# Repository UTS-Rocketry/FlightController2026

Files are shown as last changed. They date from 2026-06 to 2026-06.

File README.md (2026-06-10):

# ODIN - UTS Rocketry – Flight Controller 2026

b32aecdc31f343ea89f31d750d7f50b3_T

## Version 1.0 - First Flight Test Release

Primary avionics flight controller for the 2026 AURC rocket.

ODIN is a 3.3V STM32-based embedded flight controller designed to manage flight-state detection, onboard sensor acquisition, telemetry transmission, and flight data logging. This release represents the first hardware-and-firmware test release for an upcoming flight test.

The current firmware is intentionally simple and robust. It runs on a superloop architecture without DMA and uses a watchdog for fault recovery. The system has been tested using hardware-in-the-loop simulated flight data and has operated reliably during testing.

---

## System Overview

### Microcontroller

* STM32 F4-series microcontroller
* 3.3V logic domain
* SWD programming and debugging via ST-Link
* Optional USB device support planned for future debug and firmware workflows
* Hardware timers available for deterministic event timing
* Watchdog enabled for fault recovery

---

## Current Firmware Architecture

The first flight test firmware uses a simple superloop design.

### Current Implementation

* No RTOS
* No DMA
* Polling-based peripheral handling
* Watchdog-supervised main loop
* Deterministic flight-state logic
* Sensor sampling over shared SPI bus
* Flash-based data logging
* LoRa telemetry transmission
* Hardware-in-the-loop test data support

This architecture was selected for the first test release to reduce complexity and improve reliability during initial flight testing.

---

## Sensors

All primary sensors are currently connected on a shared SPI bus.

### Barometer

* SPI pressure sensor
* Used for altitude estimation
* Used for flight-state detection and validation
* Locally decoupled according to sensor requirements

### IMU

* SPI accelerometer and gyroscope
* Used for:

  * Boost detection
  * Apogee validation
  * Motion and orientation monitoring
* Interrupt-capable lines available for future firmware revisions

### GPS

GPS support is planned for ODIN but is not included in the current first-flight test release due to hardware issues.

Planned GPS functions include:

* Real-time position tracking
* Post-flight recovery support
* Telemetry downlink of GPS coordinates
* Position logging to onboard storage

---

## Telemetry - SX1262 LoRa

ODIN uses an SX1262-based LoRa radio for long-range telemetry transmission.

### Current Telemetry Features

* LoRa telemetry transmission enabled
* Flight-state downlink
* Sensor-derived flight data downlink
* Battery voltage downlink
* Packet scheduling is handled in the main superloop

### Planned / Future Telemetry Features

* GPS coordinate transmission
* More complete telemetry packet structure
* Configurable LoRa parameters
* Improved fault handling for radio errors

---

## Data Logging

### Current Storage

The current first flight test release uses onboard flash memory as the primary data storage medium.

Flash logging is used because the microSD card interface was dropped from the current release after wiring issues were found during testing.

### microSD Status

microSD logging was planned for this revision; however, the SD card wiring was incorrect, and the SD card interface is not used in this test release.

### Logged / Stored Parameters

The current firmware is intended to store key flight data, including:

* Timestamp or sample counter
* Raw pressure
* Calculated altitude
* IMU acceleration
* IMU gyroscope data
* Flight-state transitions
* Battery voltage
* Event flags

---

## Power Architecture

* Main system input rail
* 3.3V regulated logic rail
* ADC-based battery voltage monitoring through resistor divider
* Local decoupling at each IC
* Bulk capacitance near high-current and noise-sensitive devices
* Solid ground reference for digital logic and sensors

### Design Considerations

* All digital logic operates at 3.3V
* Shared SPI bus used for sensors and peripherals
* Short SPI traces where possible
* Source termination is considered for high-speed SPI lines
* Switching regulator noise kept away from sensitive sensor and RF sections
* Ground reference continuity is maintained across the board

---

## Programming & Debugging

### SWD Interface

SWD is the primary programming and debugging interface.

Signals:

* SWDIO
* SWCLK
* GND
* 3.3V reference
* NRST

Used for:

* Firmware flashing
* Breakpoint debugging
* Register inspection
* Fault investigation

### USB

USB support is optional and planned for future development.

Potential future uses:

* CDC virtual COM port for debug output
* DFU firmware update support
* Ground-test data streaming

---

## First Flight Test Release Notes

This release is prepared for the first ODIN flight test.

### Included

* STM32-based flight controller firmware
* Superloop firmware architecture
* Watchdog fault recovery
* SPI sensor acquisition
* Barometer-based altitude estimation
* IMU data acquisition
* LoRa telemetry transmission
* Flash-based data logging
* Battery voltage monitoring
* Hardware-in-the-loop simulated flight data testing

### Not Included in This Release

* GPS support
* microSD card logging
* DMA-based peripheral handling
* RTOS task scheduling
* Full sensor-fusion stack
* Final telemetry packet format
* Final competition firmware architecture

### Known Issues

* The microSD card interface is not used due to incorrect wiring
* GPS is not included in this release due to hardware issues
* Firmware currently uses polling rather than DMA
* Current release prioritises reliability and simplicity over final feature completeness

---

## Core Features

* Sensor initialisation and health checks
* Watchdog-supervised main loop
* Deterministic flight-state transitions
* Flash-based onboard data storage
* LoRa telemetry transmission
* Battery voltage monitoring
* Brownout and fault-awareness support
* Hardware-in-the-loop simulation data testing

---

## Development Roadmap

Future firmware and hardware revisions are expected to include:

* GPS integration
* Corrected microSD card interface
* Improved onboard logging backend
* DMA support for selected peripherals
* More complete sensor fusion
* Refined telemetry packet scheduling
* Expanded fault detection and recovery
* USB debug and DFU support
* Full competition-ready flight software

---

## Contributors
* Michael Basangan: Software Lead
* Aditya Sriram: Advisor

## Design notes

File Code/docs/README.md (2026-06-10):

# FlightComputer2026 — Documentation

Avionics flight software for **ODIN**, an STM32F405-based rocket flight computer.
This folder is the human-readable map of the firmware: what each module does, how
the system fits together, and where the code needs hardening before flight.

> **Scope.** These docs cover the *application* code under `Core/App/` plus a
> high-level view of `Core/Src/`. Vendor / auto-generated code (CubeMX init,
> ST sensor register drivers `*_reg.c`, the FatFs middleware) is intentionally
> **not** documented here — it is upstream code we did not author.

---

## Document map

| Document | What it covers | Read it when… |
|---|---|---|
| **[SYSTEM_OVERVIEW.md](SYSTEM_OVERVIEW.md)** | End-to-end architecture, execution model, data flow, the flight state machine, sensor fusion, the actuator/control story, comms, and interview talking points. | You want the big picture, or you're prepping to explain this system out loud. |
| **[CONCURRENCY_SAFETY.md](CONCURRENCY_SAFETY.md)** | Every place the code shares state across execution contexts, the memory-safety and atomicity bugs found, and a prioritized refactor plan. | You're about to make the firmware concurrent, or you want to fix the known landmines. |
| **[FSM_DISPATCH_TABLE.md](FSM_DISPATCH_TABLE.md)** | Design guidance (no code) for replacing the FSM `switch` with a function-pointer dispatch table — shape, gotchas, migration plan. | You're refactoring the flight state machine. |
| **[AppDrivers.md](AppDrivers.md)** | Hardware driver layer: sensors (baro, IMU, high-g accel), LoRa radio, flash, CAN, GPS/USB stubs. | You're touching a peripheral or adding a new one. |
| **[ApplicationLayer.md](ApplicationLayer.md)** | The "brains": sensor aggregation, Kalman filter, flight state machine, pyro/recovery logic, packet (de)serialization, and CAN tasks. (The airbrake stub was removed — control runs on KESTREL.) | You're working on flight logic, fusion, or control. |
| **[Outputs.md](Outputs.md)** | Telemetry serialization, LoRa downlink, flash data logging, LEDs/buzzer. | You're changing what leaves the board (radio, flash, indicators). |

---

## 30-second architecture summary

```
            ┌──────────────────────────────────────────────┐
            │            main.c  —  bare-metal superloop      │
            │   (no RTOS; tasks time-sliced by HAL_GetTick)   │
            └──────────────────────────────────────────────┘
                     │            │            │
        ┌────────────▼──┐  ┌──────▼──────┐  ┌──▼────────────┐
        │  Application  │  │   Outputs   │  │  AppDrivers    │
        │    Layer      │  │             │  │                │
        │ sensors/KF/   │  │ telemetry/  │  │ baro,IMU,accel │
        │ FSM/pyro/     │  │ flash log/  │  │ LoRa,flash,CAN │
        │ CAN tasks     │  │ LED+buzzer  │  │                │
        └───────────────┘  └─────────────┘  └────────────────┘
```

- **MCU:** STM32F405 @ 144 MHz, Cortex-M4F, no dynamic memory, no OS.
- **Sensing:** BMP388 barometer, LSM6DSOX IMU (accel+gyro), H3LIS331DL high-g accel — all on **SPI1**.
- **Fusion:** 3-state Kalman filter (altitude / velocity / accel-bias).
- **Decisions:** 8-state flight state machine drives pyro deployment.
- **Actuation:** pyro channels (drogue/main/aux) on this board; airbrake/fin control runs on the separate **KESTREL** control board (its own Kalman + FSM), coordinated over CAN.
- **Downlink:** LoRa (SX1276) @ 915 MHz on **SPI2**; data logging to W25Q128 16 MB flash on **SPI3**.

---

## Status legend used throughout these docs

| Symbol | Meaning |
|---|---|
| ✅ | Implemented and exercised |
| 🟡 | Implemented, not yet flight-validated / has open issues |
| 🧩 | Stub — file exists but is empty / planned |
| ⚠️ | Known bug or hazard (see [CONCURRENCY_SAFETY.md](CONCURRENCY_SAFETY.md)) |

---

*Generated from a read-through of the `dev` branch. File/line references are
accurate as of that read; re-verify after large refactors.*

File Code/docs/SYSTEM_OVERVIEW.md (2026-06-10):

# System Overview

> **Purpose of this document.** Give you a complete, accurate mental model of the
> flight computer so you can explain it confidently — including the parts a
> software/controls interviewer will probe: real-time execution, the control &
> actuation path, sensor fusion, and the engineering trade-offs you made.
>
> The last section, **[Explaining this in an interview](#explaining-this-in-an-interview)**,
> is written specifically for that conversation.

---

## 1. What it is, in one paragraph

ODIN is the flight computer for a high-power rocket. It reads three motion/pressure
sensors, fuses them into a clean estimate of **altitude and vertical velocity** with a
Kalman filter, runs an **8-state flight state machine** that decides when the rocket
has launched / burned out / reached apogee / should deploy recovery, and **fires pyro
channels** to deploy drogue and main parachutes. Throughout flight it **streams telemetry
over a LoRa radio** and **logs every sample to onboard flash**. It runs bare-metal (no
RTOS) on an STM32F405 as a single timed superloop. Active control (airbrakes/fins for
apogee targeting) runs on a **separate control board (KESTREL)**, which carries its own
sensors and runs its own copy of the same Kalman filter and state machine; the two boards
coordinate over a CAN bus.

---

## 2. Hardware platform

| Block | Part | Interface | Notes |
|---|---|---|---|
| MCU | STM32F405 (Cortex-M4F) | — | 144 MHz, hardware FPU, static memory only |
| Barometer | BMP388 | **SPI1** | Primary altitude source (pressure → altitude) |
| IMU | LSM6DSOX (accel + gyro) | **SPI1** | ±16 g accel, ±2000 dps gyro, launch/burnout detect |
| High-g accel | H3LIS331DL | **SPI1** | ±200 g — survives boost when the IMU saturates |
| Radio | LoRa SX1276 | **SPI2** + EXTI | 915 MHz telemetry downlink |
| Data log | W25Q128 NOR flash | **SPI3** | 16 MB, 64-byte records, ~262 k samples |
| SD card | (FatFs) | SPI | 🧩 present but **disabled** — wired wrong (see `main.c`) |
| Pyro out | 3× MOSFET channels | GPIO | Drogue, Main, Aux igniters |
| Pyro sense | 2× continuity | ADC1, ADC2 | Checks igniter continuity before flight |
| Indicators | Buzzer + RGB LED | GPIO / TIM2 PWM | Buzzer used; RGB PWM configured, not driven |
| Console | UART4 @ 115200 | UART | `printf` is redirected here (`_write` in `main.c`) |
| GPS | (planned) | UART5 | 🧩 stub |
| Vehicle bus | CAN2 | CAN | 🧩 peripheral init'd, driver stubbed |

**Bus allocation is a deliberate design choice** and worth calling out: the three
sensors share **SPI1**, while the **radio (SPI2)** and **flash (SPI3)** each get their
own bus. That separation means a slow radio transmit can't stall a flash write (in a
concurrent design) and the high-rate sensor reads aren't competing with bulk I/O.

---

## 3. Software architecture

The code is organized in three layers under `Core/App/`, with a thin generated
HAL/CubeMX base under `Core/Src/` and `Core/Inc/`.

```
 Core/Src/main.c   ── the superloop + all peripheral init (CubeMX) + global sensorData
        │
        ▼
 ┌─────────────────────────────────────────────────────────────────────┐
 │  Outputs/                 telemetry.c · logger(stub) · indicators.c   │  what leaves the board
 ├─────────────────────────────────────────────────────────────────────┤
 │  ApplicationLayer/        flight_sensors · kalman · flight_state      │  the brains
 │                           pyro · Lora_App · crc16 · W25Q128_HAL       │
 │                           CANTasks(stub)  ·  airbrake → KESTREL board │
 ├─────────────────────────────────────────────────────────────────────┤
 │  AppDrivers/              BMP388 · lsm6dsox · h3lis331dl · LoRa        │  hardware
 │                           W25Q128 · CAN · GPS(stub) · USB(stub)       │
 └─────────────────────────────────────────────────────────────────────┘
        │
        ▼
 ST HAL + CubeMX (Core/Src) · FatFs middleware (vendor)
```

**Layering rule of thumb:** higher layers call down, never up. A driver never knows
about flight state; the FSM never touches SPI. The one place this is slightly blurred
is telemetry/logging, which is split between `Outputs/` and `ApplicationLayer/` — noted
in [Outputs.md](Outputs.md).

---

## 4. Execution model — the superloop

There is **no operating system**. `main()` initializes everything, then runs a single
infinite loop. Inside the loop, each "task" is gated by a millisecond deadline measured
against `HAL_GetTick()` (the 1 kHz SysTick). This is a **cooperative, time-sliced
scheduler in ~30 lines** — sometimes called a "timing wheel" or "superloop."

```c
while (1) {
    uint32_t now = HAL_GetTick();

    if (now - last_imu  >= 10)  { read IMU; kalman_predict(accel, 0.01); }   // 100 Hz
    if (now - last_baro >= 40)  { read baro; kalman_update(altitude);     }   //  25 Hz
    FSM_update(&sensorData);                                                  // every pass
    if (now - last_lora  >= 200 && state >= PAD) lora_tx_telemetry(...);       //   5 Hz
    if (now - last_flash >= 40  && state >= PAD) flash_log_telemetry(...);     //  25 Hz
}
```

(Source: `Core/Src/main.c` lines ~207–259.)

**Cadence summary**

| Task | Period | Rate | Gated on |
|---|---|---|---|
| IMU read + Kalman *predict* | 10 ms | 100 Hz | always |
| Baro read + Kalman *update* | 40 ms | 25 Hz | always |
| FSM update | every pass | ~loop rate | always |
| LoRa telemetry TX | 200 ms | 5 Hz | state ≥ PAD |
| Flash logging | 40 ms | 25 Hz | state ≥ PAD |

**Interrupts.** Only one application interrupt is wired: LoRa **DIO0 → EXTI9_5**, whose
handler sets `lora_tx_done_flag` (`Lora_App.c`). SysTick runs the HAL tick (and
decrements two leftover SD-card timeout counters). Everything else is polled.

**Why this matters (and why an interviewer will ask):** a superloop is simple,
deterministic, and has no scheduler overhead or stack-per-task cost — great for a first
flight computer. Its weakness is that **the loop is only as fast as its slowest blocking
call**, and any unbounded wait hangs *everything*. Several such blocking calls exist
today and are catalogued in **[CONCURRENCY_SAFETY.md](CONCURRENCY_SAFETY.md)** — that
document is essentially the "what breaks when we add real concurrency or active control"
analysis.

---

## 5. Data flow — sensor to decision to action

```
  BMP388 ─┐                               ┌─► LoRa downlink (5 Hz)
  LSM6DSOX├─► flight_sensors ─► sensorData ┼─► flash log    (25 Hz)
  H3LIS331┘     (raw + cal)       │        └─► FSM ─► pyro fire (drogue/main)
                                  │                    │
                                  └─► Kalman filter ◄──┘  (alt + velocity feed both
                                       (alt, vel)          apogee detection and the
                                                           future control loop)
```

1. **Acquire.** `flight_sensors_update_*()` reads each sensor over SPI1, applies the
   calibration offset captured at startup, and writes engineering units into one global
   `FlightSensorData sensorData` struct.
2. **Fuse.** The IMU's vertical acceleration drives `kalman_predict()`; the barometer's
   altitude drives `kalman_update()`. The filter outputs a smoothed altitude and a
   velocity estimate that the raw sensors can't give directly.
3. **Decide.** `FSM_update()` reads `sensorData` (IMU accel, Kalman velocity/altitude)
   and advances the flight state, with debounce counters so a single noisy sample can't
   trigger a transition.
4. **Act.** State entries fire pyro channels (`pyro_fire_main/drogue`). This is the
   actuation path today.
5. **Report.** Telemetry is serialized (big-endian, CRC16-protected) and pushed to both
   the radio and flash.

The single shared `sensorData` struct is the system's "blackboard." It's fine in a
superloop (one reader/writer, sequential), but it becomes the central hazard the moment
anything runs concurrently — see the safety doc.

---

## 6. The flight state machine

`flight_state.c` implements a classic entry-action state machine. Thresholds live in
`flight_config.h` so tuning never touches logic.

```
 IDLE ──(10 s auto-arm)──► PAD ──(accel ≥ 3 g ×5)──► BOOST
                                                       │ (accel ≤ 2 g ×5, or 10 s timeout)
                                                       ▼
   LAND ◄─(low alt+vel, or timeout)─ PARAFOIL ◄─ DROGUE ◄─ APOGEE ◄─ COAST
                                                   │   ▲                 │ (vel < −0.5 m/s ×10,
                                          (main fired)│                 │  or 30 s timeout)
                                                       └─ deploy logic ──┘
```

| State | Enters when | Key action |
|---|---|---|
| `IDLE` | boot | wait; auto-arms after 10 s (`ARM_AUTO_DELAY_MS`, a temporary stand-in for a LoRa arm command) |
| `PAD` | armed | watch for launch: IMU z-accel ≥ 3 g for 5 consecutive samples |
| `BOOST` | launch detected | motor burning; watch for burnout (≤ 2 g ×5) or 10 s timeout |
| `COAST` | burnout | unpowered ascent; **the window where the KESTREL board actuates airbrakes/fins** |
| `APOGEE` | velocity goes negative (×10) or 30 s timeout | record peak altitude; fire recovery |
| `DROGUE` | after apogee deploy | descend under drogue; fire main at `MAIN_DEPLOY_ALT_M` (300 m) |
| `PARAFOIL` | main deployed | controlled descent; the parafoil is itself an actuated recovery system |
| `LAND` | low altitude + near-zero velocity, or timeout | done |

**Debounce pattern.** Every transition that's driven by a sensor requires *N consecutive*
qualifying samples (`LAUNCH_CONFIRM_SAMPLES`, `APOGEE_CONFIRM_SAMPLES`, …). This is the
software equivalent of a Schmitt trigger and is exactly the kind of robustness detail
worth pointing out.

**Redundant apogee detection.** Apogee can trigger two ways — velocity sign change *or* a
hard timeout — so a sensor dropout can't strand the vehicle without deploying recovery.
The same belt-and-suspenders pattern (event *or* timeout) appears in BOOST, COAST,
DROGUE, and PARAFOIL. That defensive design is a genuine strength to highlight.

> ⚠️ **Confirmed logic bug in the low-apogee path.** At `APOGEE` entry, if the recorded
> apogee is below `MAIN_DEPLOY_ALT_M` the code fires **main** directly — an *intentional*
> low-apogee contingency (skip the drogue phase and get the main out), otherwise it fires
> **drogue**. The intent is right, but the branch sets `main_fired = 1` and then
> transitions to `STATE_DROGUE`, whose **only** exits (`flight_state.c:148,153`) both
> require `main_fired != 1`. So the FSM gets **permanently stuck in `DROGUE`**: it never
> reaches `PARAFOIL`/`LAND`, landing is never detected, and telemetry reports `DROGUE` for
> the rest of the flight (the chute still deploys — a state-machine dead-end, not a deploy
> failure). Fix: transition straight to `STATE_PARAFOIL` in the low-apogee branch. Full
> write-up in safety doc
> [M3](CONCURRENCY_SAFETY.md#-m3--low-apogee-deploy-leaves-the-fsm-stuck-in-drogue).

---

## 7. Sensor fusion — the Kalman filter

`kalman.c` is a **3-state linear Kalman filter**:

- **State:** `[ altitude, velocity, accel_bias ]`
- **Predict** (100 Hz, from IMU): integrates acceleration into velocity and altitude,
  subtracts gravity and the estimated accelerometer bias, clamps to ±16 g, and rejects
  NaN/Inf inputs.
- **Update** (25 Hz, from baro): corrects the state toward the measured altitude; the
  filter learns the accelerometer bias over time, which is what keeps the integrated
  velocity from drifting.
- **Covariance** `P` is a full 3×3 propagated as `P = F·P·Fᵀ + Q`, with the
  measurement step `K = P·Hᵀ·S⁻¹`.

**Why fuse at all?** The barometer gives absolute altitude but is noisy and slow; the
accelerometer is fast but integrating it drifts. Fusing them yields a velocity estimate
good enough to detect apogee — and, importantly, good enough to **feed a control loop**.
That velocity/altitude estimate is the natural feedback signal for airbrake/fin control.

> Implementation notes: `dt` is now computed from real elapsed time (`main.c:211`, fixed
> since the first review); the process/measurement noise (`Q`/`R`) are still fixed
> constants — a reasonable v1 choice and an easy tuning lever to mention.

---

## 8. The control and actuation path

> *The most relevant section for a controls / actuator software role.*

This is the part to be fluent in, since the role is about actuator/fin-control software.
It's useful to frame the vehicle's actuation as **three tiers**, and to be clear which
board owns each — **ODIN** (this flight computer) vs. **KESTREL** (the control board):

### Tier 1 — Pyrotechnic actuation (implemented ✅)

`pyro.c` drives three igniter channels through MOSFETs and reads two ADC continuity
checks. The FSM commands them at the right flight phase. This is *open-loop, one-shot*
actuation: fire for a fixed pulse (`PYRO_FIRE_DURATION_MS = 500 ms`) and latch a "fired"
flag so it can't double-fire.

> ⚠️ `pyro_fire_*()` holds the line high with a **blocking `HAL_Delay(500)`**, so firing
> stalls the entire superloop for half a second — no sensor reads, no estimation, no
> telemetry during that window. For pyro that's *arguably* tolerable; for a closed-loop
> actuator it is not. This is the cleanest example of why the loop must go non-blocking
> before active control is added. (Catalogued as **C1** in the safety doc.)

### Tier 2 — Continuous control surfaces / airbrakes ⟶ *runs on the KESTREL control board, not ODIN*

Active airbrake/fin control does **not** run on this flight computer. It lives on a
**separate control board (KESTREL)** with its own sensors that runs **its own copy of the
same Kalman filter and flight state machine**. ODIN's job is sensing, estimation, recovery
(pyro), logging and downlink; KESTREL independently estimates state and drives the control
surfaces. *(The empty `ApplicationLayer/ControlLoop/airbrake.{c,h}` stubs in this repo are
therefore removed (staged for deletion) — that code belongs on KESTREL.)*

**Why duplicate the KF + FSM on both boards?** So the deploy decision doesn't depend on
ODIN being alive or the CAN link being up — and, critically, so KESTREL can **gate airbrake
deployment to the `COAST` state on its own**. Airbrakes must never deploy during boost
(high-g) or the airframe could be damaged; by independently detecting burnout→COAST,
KESTREL has a self-contained safety interlock. This is **redundant / distributed
estimation**: two boards reach the flight-phase decision independently.

The controller itself (on KESTREL): feedback = Kalman altitude/velocity (+ gyro for
attitude); setpoint = a target apogee; output = a PWM servo command modulating drag to
bleed excess energy (classic apogee-targeting). A PID or gain-scheduled law on
velocity-vs-altitude is the usual approach. Authority is gated to `COAST`.

**What to say in an interview:** *"Active control runs on a dedicated board that
independently re-derives flight phase with the same Kalman filter + state machine, so the
airbrakes can only deploy in coast — even if the main flight computer or the bus drops out.
That redundant-estimation interlock is what stops a control surface from firing under boost
loads."* That shows you think about actuator **safety interlocks** and **failure
independence**, not just the control law — and that **control is only as good as the
real-time guarantees underneath it**.

### Tier 3 — Distributed actuation over CAN (planned 🧩 — `CANTasks/can_tasks.c`)

The CAN layer (`AppDrivers/CAN/CAN.h`) defines a small **vehicle bus protocol**:

- **Nodes:** `ODIN` (this flight computer), `KESTREL` (control/actuator board),
  `RAVEN` (camera), `HUGINN` (CAN sniffer/debug).
- **Messages:** heartbeat, FSM-state broadcast, **KESTREL commands** (activate /
  deactivate / **deploy parafoil**), camera commands, **actuator status**
  (`airbrake_pos`, `parafoil_dep`), ACK, error.
- **Addressing:** 11-bit ID packed as `(node << 7) | msg`.

The split the message set implies: **ODIN broadcasts flight state + estimation and issues
high-level commands (e.g. deploy-parafoil); KESTREL runs its own estimation, drives the
airbrakes/fins, and reports `airbrake_pos` / `parafoil_dep` status back.** Both boards
estimate independently (see Tier 2) — CAN coordinates them, but neither blindly trusts the
other for the safety-critical phase decision. That's a textbook *distributed-controls* bus
pattern. The peripheral is initialized (`CAN2` in `main.c`) but `CAN.c` and `can_tasks.c`
are not yet implemented — `CANTasks/` stays on ODIN (it still broadcasts state).

> ⚠️ Landmine to fix before wiring CAN in: `CAN.h` and `Lora_App.h` both define enums
> named `IDLE`, `ARMED`, … — including both in one translation unit won't compile.
> See safety doc item **C8**.

---

## 9. Communications

### LoRa telemetry downlink (✅, 🟡)

- SX1276 at **915 MHz, SF7, 125 kHz BW, CR 4/5, +17 dBm (PA_BOOST), CRC on** (`Lora_App.c`).
- **5 Hz** downlink once armed.
- Packet: a fixed **58-byte** frame — 3-byte header (sync `0xAA`, type, sequence),
  13 big-endian float fields (alt, pressure, temp, 3× high-g, 3× IMU accel, 3× gyro,
  Kalman velocity), 1 state byte, **CRC16-CCITT** (poly `0x1021`) over the first 56 bytes.
- Serialization is hand-rolled and endian-explicit (`telemetry_serializer` in
  `Lora_App.c`) — good practice for a wire format that a ground station must parse.

> ✅ The earlier `lora_tx_telemetry` buffer overflow (**M1**) is now fixed (`buff[62]`). The
> remaining radio issues are the **busy-poll that ignores the DIO0 done-interrupt**
> (**C2**/**C3**) and the new **RX command path blocking ≤1 s** (**N1**). There's also an
> authenticated uplink command path and a pre-launch continuity broadcast now (see
> [Outputs.md](Outputs.md)).

### CAN vehicle bus (🧩)

See [§8 (Tier 3)](#8-the-control-and-actuation-path).
Protocol defined, transport not yet implemented.

---

## 10. Memory & data logging

- **No heap.** Everything is statically allocated — global structs, file-scope `static`
  driver state, stack buffers. No `malloc`, no fragmentation, deterministic footprint.
  This is the right call for flight code and worth stating plainly.
- **Flash log:** `W25Q128_HAL.c` writes fixed **64-byte records** sequentially to the
  16 MB NOR flash, auto-erasing each 4 KB sector as it reaches it. ~262 000 records ≈
  ~2.9 hours at 25 Hz. `flash_dump_serial()` replays them over UART for post-flight
  analysis.
- **SD card:** a FatFs + SPI SD path exists (`fatfs_sd.c`) but is **disabled** — the
  comment in `main.c` notes it's wired wrong. The leftover `Timer1/Timer2` SysTick
  counters belong to this dead path.

---

## 11. Key engineering trade-offs (have an opinion on each)

| Decision | Chosen | Why it's defensible | The cost / when you'd change it |
|---|---|---|---|
| **Superloop vs RTOS** | Superloop | Simple, deterministic, no scheduler/stack overhead, easy to reason about for v1 | One blocking call stalls everything; no priority. Move to RTOS (or at least non-blocking + ISR/DMA) when adding closed-loop control. |
| **Polling vs interrupt/DMA SPI** | Polling | Straightforward, no race windows in a superloop | CPU burns cycles waiting; bus-bound. DMA + ISR needed for headroom once a control task exists. |
| **Static vs dynamic memory** | Static | No fragmentation, bounded RAM, flight-safe | Less flexible; you size for worst case. (Correct trade for avionics.) |
| **One shared `sensorData`** | Global blackboard | Zero copies, simple in a single-context loop | Becomes a data race the instant anything is concurrent; needs snapshotting/double-buffer. |
| **Hand-rolled telemetry serializer** | Manual big-endian | Explicit, portable wire format, no library | Verbose, easy to get a length wrong (and one is — see C2). |
| **Three sensors on one SPI bus** | SPI1 shared | Saves pins/buses; radio & flash isolated | Needs bus arbitration if reads ever move off the single loop. |

---

## 12. Explaining this in an interview

### The 60-second pitch
> "I built the flight software for a rocket flight computer on an STM32F405. It fuses a
> barometer and two accelerometers through a Kalman filter into an altitude/velocity
> estimate, runs an 8-state flight state machine that decides launch, burnout, apogee and
> recovery, and fires the parachute pyros. It logs everything to flash and streams
> telemetry over LoRa. It's bare-metal — a single timed superloop, no RTOS, all static
> memory. Active control — airbrakes for apogee targeting — runs on a separate control
> board that re-derives flight phase independently, coordinated over CAN."

### If they push on the **control / actuator** angle (your role)
- Lead with the **three actuation tiers** (§8): pyro recovery on ODIN, airbrake control on
  the KESTREL board, distributed CAN actuation tying them together.
- Emphasize that **the hard prerequisites for control already exist and work**: a clean
  velocity estimate and a state machine that defines exactly when actuation is authorized
  (the COAST window). The control board reuses both, running them **independently** so it
  can gate airbrake deployment to coast on its own — a **redundant-estimation safety
  interlock** that prevents deploying a control surface under boost (high-g) loads.
- Show you understand the *systems* dependency: **"a controller is only as good as the
  real-time loop under it."** The current superloop has blocking calls (pyro `HAL_Delay`,
  LoRa busy-poll) that would inject jitter into a control task — so step one toward
  active control is making the loop non-blocking / moving I/O to DMA+ISR. You can point
  to the exact lines.
- Mention the **CAN protocol design** (ODIN↔KESTREL, `airbrake_pos` feedback) as
  evidence you think about distributed actuation and closed-loop status, not just one MCU.

### If they push on **real-time / concurrency**
- Explain the superloop scheduler and its cadence table (§4), then be honest about its
  limits and that you've already catalogued them ([CONCURRENCY_SAFETY.md](CONCURRENCY_SAFETY.md)).
- Best signal you can give: *"Here are the exact shared-state hazards and the order I'd
  fix them in."* Walk the priority list. Interviewers love a candidate who already knows
  where their own bugs are.

### If they push on **estimation**
- 3-state KF, why fuse (baro = absolute but noisy/slow, accel = fast but drifts), how the
  bias state absorbs accelerometer offset. Mention the fixed `dt` and fixed noise as the
  obvious tuning improvements.

### Likely hard questions — and honest answers
| Question | Strong answer |
|---|---|
| "What happens if a sensor hangs?" | Today the read loops busy-wait with no timeout, so it would hang the whole computer — that's my #1 fix (add bounded timeouts; safety doc C4). |
| "Why no RTOS?" | Simplicity and determinism for v1; I'd adopt one (or non-blocking + DMA) precisely when adding the control task, because that needs a fixed-rate, jitter-bounded slot. |
| "How do you know apogee?" | Kalman velocity crossing negative, debounced over 10 samples, **with** a timeout fallback so a baro dropout still deploys recovery. |
| "Is your telemetry robust?" | CRC16 per packet and a sequence number so the ground station detects drops/corruption. (I also have a buffer-length bug in the TX path I've already identified.) |
| "How would you add airbrakes?" | On the KESTREL control board, not the flight computer: reuse the same Kalman + FSM so it independently knows it's in COAST, run a controller on velocity/altitude, output PWM to a servo, keep the loop non-blocking for a fixed rate. Gating to COAST is the key safety interlock — never actuate under boost. |

### What I'd build next (shows direction)
1. Make the loop non-blocking (kill `HAL_Delay` in pyro/buzzer; ISR/DMA for SPI & LoRa).
2. Add bounded timeouts + fault states to every sensor read.
3. Consume the LoRa DIO0 done-interrupt (C2/C3) and de-block the RX command path (N1).
4. Implement the airbrake control loop on KESTREL (its own KF+FSM, gated to the COAST window).
5. Bring up the CAN link to KESTREL for distributed actuation.

---

## 13. Glossary

| Term | Meaning |
|---|---|
| **ODIN / KESTREL / RAVEN / HUGINN** | CAN node names: flight computer / control board / camera / bus sniffer |
| **Superloop** | A single `while(1)` that runs all tasks cooperatively, no OS |
| **Apogee** | Highest point of flight; where drogue typically deploys |
| **Drogue / Main** | Small stabilizing chute (deploys high) / main chute (deploys low) |
| **Pyro** | Pyrotechnic igniter channel that cuts a line or deploys a chute |
| **ODR / OSR** | Output Data Rate / Oversampling Ratio (sensor config) |
| **EXTI** | STM32 external interrupt line (used for LoRa DIO0) |
| **SF / BW / CR** | LoRa Spreading Factor / Bandwidth / Coding Rate |

---

*See [CONCURRENCY_SAFETY.md](CONCURRENCY_SAFETY.md) for the detailed hazard list this
overview references, and the per-layer docs for module-level API detail.*

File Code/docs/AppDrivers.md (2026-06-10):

# AppDrivers — Hardware Driver Layer

`Core/App/AppDrivers/`

The lowest layer of our own code: one module per physical peripheral. Each driver owns a
**handle struct** (which SPI bus, which CS pin) and exposes a small `HAL_StatusTypeDef`
API. Drivers know nothing about flight state — they just move bytes to and from silicon.

```
AppDrivers/
├── Sensors/     BMP388 (baro) · LSM6DSOX (IMU) · H3LIS331DL (high-g)   ── all on SPI1
├── LoRa/        SX1276 radio                                            ── SPI2 + EXTI
├── Memory/      W25Q128 NOR flash · fatfs_sd (SD, disabled)            ── SPI3 / SPI
├── CAN/         vehicle-bus protocol definitions                       ── CAN2  🧩
├── GPS/         🧩 empty stub                                           ── UART5
└── USB/         🧩 empty stub
```

> **Driver contract (the shared pattern).** Every device driver takes a pointer to a
> handle holding `SPI_HandleTypeDef *hspi` + `cs_port`/`cs_pin`. A private
> `platform_read/platform_write` pulls CS low, sends the register address, transfers, and
> raises CS. Read/write is distinguished by setting the register's MSB(s). This keeps the
> ST vendor `*_reg` driver layer hardware-agnostic.

---

## Sensors/

Three motion/pressure sensors, **all sharing SPI1** (distinct CS pins). They cover
complementary regimes — see [SYSTEM_OVERVIEW §2](SYSTEM_OVERVIEW.md#2-hardware-platform).

The ST sensors (LSM6DSOX, H3LIS331DL) ship with vendor register drivers
(`lsm6dsox_reg.c/.h`, `h3lis331dl_reg.c/.h`) — **not documented here**, they're upstream.
What *we* wrote are the thin `_hal.c` glue files that bind those drivers to our SPI + CS
and add init/calibration/read helpers.

### BMP388 — barometric altimeter ✅
**Files:** `Sensors/BMP388.c` (.h), self-contained driver (no vendor layer).
**Bus/CS:** SPI1 / `CSBarometer`.

| Function | Purpose |
|---|---|
| `BMP388_Init` | Verify chip ID, soft-reset, configure OSR/IIR/ODR, load factory calibration |
| `BMP388_FindGroundPressure` | Capture ground reference pressure at startup (altitude zero) |
| `BMP388_ReadRawPressTempTime` | Raw burst read of pressure/temperature/sensor-time |
| `BMP388_CompensateRawPressTemp` | Apply the datasheet compensation polynomials |
| `BMP388_FindAltitude` | Pressure → altitude (barometric formula vs. ground pressure) |
| `BMP388_ExternalReadFunction` | One-call read used by `flight_sensors`: returns pressure, temp, altitude |

**Notes:** the compensation math uses the float `Calib_data` struct loaded at init. The
data-ready wait in the read path is an unbounded `do/while` (see
[CONCURRENCY_SAFETY C4](CONCURRENCY_SAFETY.md#-c4--unbounded-sensor-busy-waits-with-no-timeout)).

### LSM6DSOX — 6-axis IMU (accel + gyro) ✅
**Files:** `Sensors/lsm6dsox_hal.c` (our glue) + `lsm6dsox_reg.c/.h` (ST, vendor).
**Bus/CS:** SPI1 / `CS_IMU`.

| Function | Purpose |
|---|---|
| `lsm6dso_init` | ID check, reset, disable I3C, **±16 g** accel, **±2000 dps** gyro, gyro LPF; ODR set to **104 Hz** |
| `lsm6dso_Calib` | Average 100 samples to capture accel/gyro zero offsets (Z accel referenced to 1 g) |
| `lsm6dso_ExternalReader` | Read raw accel + gyro (used every IMU pass) |

**Notes:** code comments say "416 Hz" but the calls set `*_ODR_104Hz` — a comment/code
mismatch worth tidying. The Z-accel from this IMU is what drives launch/burnout detection
and the Kalman predict step. `platform_read/write` here **swallow SPI errors**
(always return 0) — [CONCURRENCY_SAFETY C5](CONCURRENCY_SAFETY.md#-c5--spi-errors-are-silently-swallowed).
The data-ready wait has no timeout (worst case of [C4](CONCURRENCY_SAFETY.md#-c4--unbounded-sensor-busy-waits-with-no-timeout) — no delay either).

### H3LIS331DL — ±200 g high-g accelerometer ✅
**Files:** `Sensors/h3lis331dl_hal.c` (our glue) + `h3lis331dl_reg.c/.h` (ST, vendor).
**Bus/CS:** SPI1 / `CSAccelerometer`.

| Function | Purpose |
|---|---|
| `h3lis331dl_init` | ID check, boot, **±200 g** full scale, HP filter off, **100 Hz** ODR |
| `h3lis331dl_Calibration` | Average 100 samples for offsets (Z referenced to 1 g) |
| `h3lis331dl_externalRead` | Read raw 3-axis acceleration |

**Why it exists:** during boost the airframe can exceed the LSM6DSOX's ±16 g range; the
H3LIS keeps a valid acceleration reading when the IMU saturates. Same C4/C5 notes as the
IMU apply.

---

## LoRa/

### SX1276 — 915 MHz LoRa radio ✅ 🟡
**Files:** `LoRa/LoRa.c` (.h).
**Bus/CS:** SPI2 / `LoRaNssPin`; reset on `LoRaResetPin`; **DIO0 → EXTI9_5** for TX/RX done.

A from-scratch SX1276 driver (register map + ops). Configured by the app layer at 915 MHz,
SF7, 125 kHz, CR 4/5, +17 dBm PA_BOOST, CRC on, explicit header.

| Function | Purpose |
|---|---|
| `lora_init` | Reset, set LoRa mode, program frequency/SF/BW/CR/power/CRC/sync/preamble |
| `lora_TX` | Load FIFO, transmit, **busy-poll** `IRQ_TX_DONE` until done or timeout |
| `lora_RX` / `lora_receive_cont` / `lora_receive_cont_poll` | Single & continuous receive |
| `lora_sleep` / `lora_standby` | Power-mode control |
| `lora_packet_rssi` / `lora_packet_snr` / `lora_version` | Link diagnostics |

**Notes:** `lora_TX` busy-polls the IRQ register
([C2](CONCURRENCY_SAFETY.md#-c2--lora_tx-busy-polls-up-to-1-s)) even though the DIO0
done-interrupt is wired up but unused
([C3](CONCURRENCY_SAFETY.md#-c3--lora-tx-done-interrupt-is-set-up-but-never-consumed)).
Receive is implemented but the flight build only transmits.

---

## Memory/

### W25Q128 — 16 MB NOR flash ✅
**Files:** `Memory/W25Q128.c` (.h).
**Bus/CS:** SPI3 / `CSFlashmMemory`.

Clean, low-level driver for the Winbond W25Q128JV. **This is the reference for how to do a
blocking driver right** — note `W25Q128_WaitBusy` uses a real `HAL_GetTick()` timeout
(the pattern the sensor drivers should copy for
[C4](CONCURRENCY_SAFETY.md#-c4--unbounded-sensor-busy-waits-with-no-timeout)).

| Function | Purpose |
|---|---|
| `W25Q128_Init` | CS-high, release power-down, verify JEDEC ID (`EF 40 18`) |
| `W25Q128_ReadJEDECID` | Identity read |
| `W25Q128_ReadData` | Read N bytes from a 24-bit address |
| `W25Q128_PageProgram` | Program up to a 256-byte page (must not cross a page boundary) |
| `W25Q128_SectorErase` / `W25Q128_ChipErase` | 4 KB sector / full-chip erase |
| `W25Q128_WaitBusy` | Poll BUSY with timeout ✅ |
| `W25Q128_PowerDown` / `ReleasePowerDown` | Power management |

Geometry constants (page 256 B, sector 4 KB, 16 MB total) live in `W25Q128.h`. The
flight-facing logging wrapper is `ApplicationLayer/.../W25Q128_HAL.c` — see
[ApplicationLayer.md](ApplicationLayer.md) and [Outputs.md](Outputs.md).

### fatfs_sd — SD card over SPI 🧩 (disabled)
**Files:** `Memory/fatfs_sd.c` (.h).

A Chan-FatFs SPI SD diskio implementation. **Currently disabled** — `main.c` notes the SD
is wired wrong and `f_mount` is commented out. The `volatile uint16_t Timer1/Timer2`
counters defined here (decremented in SysTick) are this driver's I/O timeouts and are
otherwise dead weight right now. Treat this module as parked until the hardware is fixed.

---

## CAN/  🧩

### Vehicle-bus protocol
**Files:** `CAN/CAN.h` (defined), `CAN/CAN.c` (**empty stub**).
**Bus:** CAN2 (peripheral initialized in `main.c`).

No transport code yet, but the **protocol is fully specified** in the header and is the
backbone of the planned distributed-actuation design:

- **Nodes:** `ODIN` (flight computer), `KESTREL` (control/actuator board), `RAVEN`
  (camera), `HUGINN` (sniffer).
- **Messages:** heartbeat, FSM-state broadcast, KESTREL commands (activate / deactivate /
  deploy-parafoil), RAVEN/camera commands, ACK, actuator status (`airbrake_pos`,
  `parafoil_dep`), error.
- **ID format:** `CAN_ID(node,msg) = (node << 7) | msg` (11-bit standard ID).

See [SYSTEM_OVERVIEW §8 (Tier 3)](SYSTEM_OVERVIEW.md#8-the-control-and-actuation-path)
for how this fits the control story, and
[CONCURRENCY_SAFETY C8](CONCURRENCY_SAFETY.md#-c8--duplicate-enum-definitions-collide-across-headers)
for the enum-collision fix needed before implementing it.

---

## GPS/ and USB/  🧩

Empty stubs (`GPS.c/.h`, `USBC.c/.h`). GPS is intended on **UART5**; a `GPSPacket` type
is already reserved in `Lora_App.h` for when position data joins the downlink. USB is a
placeholder (the USB OTG peripheral is initialized in `main.c` but unused).

---

## At-a-glance status

| Driver | Bus | Status |
|---|---|---|
| BMP388 | SPI1 | ✅ |
| LSM6DSOX | SPI1 | ✅ (C4/C5 notes) |
| H3LIS331DL | SPI1 | ✅ (C4/C5 notes) |
| SX1276 LoRa | SPI2 + EXTI | ✅ 🟡 (C2/C3) |
| W25Q128 flash | SPI3 | ✅ (reference impl) |
| fatfs_sd | SPI | 🧩 disabled |
| CAN | CAN2 | 🧩 protocol only |
| GPS / USB | UART5 / USB | 🧩 stubs |

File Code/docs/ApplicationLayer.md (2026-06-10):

# ApplicationLayer — Flight Logic & Fusion

`Core/App/ApplicationLayer/`

The "brains" of the flight computer. This layer turns raw driver reads into a fused state
estimate, decides what phase of flight the vehicle is in, and commands actuation. It calls
*down* into [AppDrivers](AppDrivers.md) and is called *from* the `main.c` superloop.

```
ApplicationLayer/
├── ApplicationHALS/      flight_sensors · kalman · pyro · Lora_App · packets · W25Q128_HAL · crc16
├── FlightStateMachine/   flight_state · flight_config   (refactor → docs/FSM_DISPATCH_TABLE.md)
├── ControlLoop/          airbrake   ❌  ← REMOVED (staged): airbrake control runs on the KESTREL board
└── CANTasks/             can_tasks  🧩  ← CAN comms tasks live here (stays on ODIN)
```

---

## ApplicationHALS/

"HAL" here means *our* application-level hardware abstraction — one tier above the device
drivers. Each module wraps one or more drivers into a flight-friendly API.

### flight_sensors — sensor aggregation & calibration ✅
**Files:** `ApplicationHALS/flight_sensors.c` (.h).

Owns the three sensor handles and the calibration offsets, and presents the unified
`FlightSensorData` struct that the whole system reads/writes.

| Function | Purpose |
|---|---|
| `flight_sensors_init` | Init baro + capture ground pressure, init high-g accel + calibrate, init IMU + calibrate. Returns first failure. |
| `flight_sensors_update_baro` | Read BMP388 → `pressure`, `temperature`, `altitude` (25 Hz) |
| `flight_sensors_update_IMU_accel` | Read H3LIS + LSM6DSOX → high-g, IMU accel, gyro in engineering units, offset-corrected (100 Hz) |

**`FlightSensorData`** (`flight_sensors.h`) is the system blackboard: altitude, pressure,
temperature, velocity, high-g XYZ (mg), IMU accel XYZ (mg), gyro XYZ (mdps),
`kalman_altitude`, `kalman_velocity`, and `flight_state`. It is instantiated once as a
global in `main.c`.

> Footguns: there are **two** velocity fields (`velocity` and `kalman_velocity`) — only
> `kalman_velocity` is populated/used. The struct is shared with no snapshot protection
> ([CONCURRENCY_SAFETY C6](CONCURRENCY_SAFETY.md#-c6--the-sensordata-blackboard-is-not-snapshot-safe)).

### kalman — 3-state sensor-fusion filter ✅
**Files:** `ApplicationHALS/kalman.c` (.h).

Linear Kalman filter estimating **[altitude, velocity, accel_bias]** with a full 3×3
covariance. See [SYSTEM_OVERVIEW §7](SYSTEM_OVERVIEW.md#7-sensor-fusion--the-kalman-filter)
for the math intuition.

| Function | Called | Purpose |
|---|---|---|
| `kalman_init` | startup | Zero the state, seed covariance diagonal, set Q/R noise constants |
| `kalman_predict(accel_z_mg, dt)` | 100 Hz (IMU) | Integrate accel → velocity/altitude; subtract gravity + bias; clamp ±16 g; reject NaN/Inf |
| `kalman_update(baro_altitude)` | 25 Hz (baro) | Correct state toward measured altitude; learn accel bias |
| `kalman_get_altitude` / `kalman_get_velocity` | reads | Latest estimate (fed back into `sensorData`) |

**Inputs validated** (NaN/Inf rejected; `dt` must be `0 < dt ≤ 1`) — good defensive
coding. **Improvement levers:** `dt` is passed as a hard-coded `0.01` from `main.c`
([R2](CONCURRENCY_SAFETY.md#-r2--kalman-dt-is-hard-coded)); Q/R are fixed constants;
`ground_altitude`/`kalman_get_ground` are declared in the header but unused.

### pyro — pyrotechnic actuation ✅
**Files:** `ApplicationHALS/pyro.c` (.h).

Drives three igniter channels (drogue/main/aux) and a buzzer via GPIO, with two ADC
continuity checks. This is the **implemented actuation path** (Tier 1 in
[SYSTEM_OVERVIEW §8](SYSTEM_OVERVIEW.md#8-the-control-and-actuation-path)).

| Function | Purpose |
|---|---|
| `pyro_init` | Drive all igniters + buzzer low (safe state) |
| `pyro_check_drogue` / `pyro_check_main` | ADC continuity check vs. `PYRO_CONTINUITY_THRESHOLD` |
| `pyro_fire_drogue` / `pyro_fire_main` / `pyro_fire_aux` | Pulse the channel for `PYRO_FIRE_DURATION_MS` (500 ms) |
| `pyro_buzzer_on` / `pyro_buzzer_off` | Buzzer control |

> ⚠️ `pyro_fire_*` holds the line high with a **blocking `HAL_Delay(500)`**, freezing the
> superloop — [CONCURRENCY_SAFETY C1](CONCURRENCY_SAFETY.md#-c1--pyro-and-buzzer-block-the-loop-with-hal_delay).
> This is the cleanest reason to make the loop non-blocking before adding closed-loop
> control. The continuity checks (`pyro_check_*`) are defined but not yet called by the
> FSM — wiring them into a pre-arm check is a good easy win.

### Lora_App — radio config & DIO0 ISR ✅ 🟡
**Files:** `ApplicationHALS/Lora_App.c` (.h).

Bridges the SX1276 driver to the flight app. *(The packet **wire formats** and serializers
were moved out to `packets.c` — see the packets module below. `Lora_App` now just holds the
radio config, the DIO0 ISR, and `lora_App_Init`.)*

| Symbol | Purpose |
|---|---|
| `lora_App_Init` | Fill the SX1276 handle + LoRa config (915 MHz / SF7 / 125 kHz / +17 dBm); call `lora_init` |
| `HAL_GPIO_EXTI_Callback` | DIO0 ISR — sets `lora_tx_done_flag` |
| `FlightStateLoRa` enum | LoRa-side flight-state codes (distinct from `FlightState_t`) |

> Notes (still open): the DIO0 ISR sets `lora_tx_done_flag` but nobody reads it, and the
> header declares a misspelled `HAL_GPIOEXTI_Callback` prototype that doesn't match the
> `HAL_GPIO_EXTI_Callback` implementation
> ([C3](CONCURRENCY_SAFETY.md#-c3--lora-tx-done-interrupt-is-set-up-but-never-consumed)).
> `Lora_App.h` also still defines the duplicate `IDLE/ARMED/…` enum that collides with
> `CAN.h` ([C8](CONCURRENCY_SAFETY.md#-c8--duplicate-enum-definitions-collide-across-headers)).

### W25Q128_HAL — flash logging policy ✅
**Files:** `ApplicationHALS/W25Q128_HAL.c` (.h).

Turns the raw flash driver into an append-only record log.

| Function | Purpose |
|---|---|
| `flash_memory_init` | Bind handle to SPI3 + CS, init the chip |
| `flash_sanity_check` | Print JEDEC ID (expect `EF 40 18`) |
| `flash_log_packet(buff, len)` | Append a 64-byte record; auto-erase each 4 KB sector at its boundary; track write address + count |
| `flash_read_record(index, …)` | Random-access read of record N (for dump/replay) |
| `flash_get_record_count` | Records written this session |

**Policy:** fixed 64-byte records from address 0; ~262 144 max (16 MB / 64). `flash_write_addr`
/ `flash_record_count` are module statics (single-writer today; note for concurrency).
The flight-facing wrapper that builds the record is `flash_log_telemetry` in
[Outputs/Telemetry](Outputs.md).

### packets — packet types & (de)serialization ✅
**Files:** `ApplicationHALS/packets.c` (.h).

Owns the **wire formats** (moved here from `Lora_App.c`). Defines `HeaderPacket`,
`TelemetryPacket`, `ContinuityPacket`, `CommandPacket`, the `PacketType` / `CommandID`
enums, and the (de)serializers:

| Function | Purpose |
|---|---|
| `telemetry_serializer` | 58-byte big-endian telemetry frame + CRC16 |
| `continuity_serializer` | 8-byte pyro-continuity frame + CRC16 |
| `command_deserializer` | Validate + decode a ground command (sync + type + `0xBE` auth + CRC16) |

The command path is properly **authenticated** (auth byte + CRC) — good design. Two nits:
the `CommandPacket` struct field order disagrees with the byte offsets `command_deserializer`
actually reads, and `ContinuityPacket.aux` is declared but hardcoded to `0` in the
serializer — see [CONCURRENCY_SAFETY N3](CONCURRENCY_SAFETY.md#-n3--commandpacket-struct-disagrees-with-the-deserializers-wire-layout).

### crc16 — frame integrity ✅
**Files:** `ApplicationHALS/crc16.c` (.h).

CRC16-CCITT (poly `0x1021`), bit-serial, used to protect every telemetry/flash frame.
`crc16(seed, data, len)` — the `len` param is `uint64_t` (oversized for a 32-bit MCU, but
harmless). A sequence number + CRC per packet is what lets the ground station detect drops
and corruption.

---

## FlightStateMachine/

### flight_state — the 8-state flight FSM ✅
**Files:** `FlightStateMachine/flight_state.c` (.h).

Entry-action state machine over `FlightState_t` { IDLE, PAD, BOOST, COAST, APOGEE, DROGUE,
PARAFOIL, LAND }. Full transition table and the deployment-logic caveat are in
[SYSTEM_OVERVIEW §6](SYSTEM_OVERVIEW.md#6-the-flight-state-machine).

| Function | Purpose |
|---|---|
| `FSM_init` | Zero context, start in `IDLE` |
| `FSM_update(sensorData)` | Run current state's logic; called every superloop pass |
| `FSM_get_state` | Current state (copied into `sensorData` and telemetry) |

**Design highlights:** debounced transitions (N consecutive samples via the
`*_CONFIRM_SAMPLES` configs); **event-or-timeout** redundancy in every dynamic state so a
sensor dropout can't strand the vehicle; pyro fire is gated to state entries with
`main_fired`/`drogue_fired` flags. Context (`FSM_Context_t ctx`) is a file static
(single-context today). Per-state debounce counters are function-`static` locals — fine in
the superloop, not reentrant.

> 🔧 **Planned refactor:** replace the `switch` with a **function-pointer dispatch table** —
> full design guidance, gotchas, and migration plan in
> [FSM_DISPATCH_TABLE.md](FSM_DISPATCH_TABLE.md). Moving the debounce counters into
> `FSM_Context_t` as part of that also fixes the fact that `FSM_init` can't currently reset
> those statics.

> ⚠️ Logic bug: the low-apogee branch fires main then transitions to `DROGUE`, whose exits
> all require `main_fired != 1`, so the FSM gets **stuck in `DROGUE`** (the intentional
> low-apogee main-deploy targets the wrong next state)
> ([M3](CONCURRENCY_SAFETY.md#-m3--low-apogee-deploy-leaves-the-fsm-stuck-in-drogue)) —
> fix by transitioning to `PARAFOIL` in that branch.

### flight_config — all the tunable thresholds ✅
**Files:** `FlightStateMachine/flight_config.h`.

Pure `#define` table — **the one file you touch to tune flight behavior**, with no logic:

| Group | Constants |
|---|---|
| Launch detect | `LAUNCH_ACCEL_THRESHOLD_MG` (3 g), `LAUNCH_CONFIRM_SAMPLES` (5) |
| Burnout detect | `BURNOUT_ACCEL_THRESHOLD_MG` (2 g), `BURNOUT_CONFIRM_SAMPLES` (5) |
| Apogee detect | `APOGEE_VELOCITY_THRESHOLD` (−0.5 m/s), `APOGEE_CONFIRM_SAMPLES` (10) |
| Deploy | `MAIN_DEPLOY_ALT_M` (300 m) |
| Landing | `LAND_VELOCITY_THRESHOLD` (0.5 m/s), `LAND_ALT_THRESHOLD_M` (10 m) |
| Timeouts | `BOOST` 10 s, `COAST` 30 s, `DROGUE` 5 s, `PARAFOIL` 5 min |
| Arming | `ARM_AUTO_DELAY_MS` (10 s — temporary auto-arm; replace with a LoRa/CAN arm command) |

Keeping thresholds out of `flight_state.c` is good practice — tuning never risks a logic
regression.

---

## ControlLoop/  ❌ — *to be removed; airbrake control lives on the KESTREL board*

**Files:** `ControlLoop/airbrake.c` (.h) — **empty stubs, slated for removal.**

Airbrake/fin control does **not** run on this flight computer. It runs on the separate
**KESTREL control board**, which has its own sensors and runs its **own copy of the same
Kalman filter and FSM**, deploying airbrakes only in the `COAST` state — independently of
ODIN — so a control surface can never fire under boost (high-g) loads even if ODIN or the
CAN link drops. These empty stubs should be deleted from the flight computer to keep the
ODIN (sense/estimate/recover) vs. KESTREL (control) responsibility split clean.

See [SYSTEM_OVERVIEW §8 (Tier 2)](SYSTEM_OVERVIEW.md#8-the-control-and-actuation-path) for
the full distributed-control / redundant-estimation framing.

---

## CANTasks/  🧩

**Files:** `CANTasks/can_tasks.c` (.h) — **empty stubs.**

Intended home for the CAN communication tasks: heartbeat, broadcasting FSM state,
commanding the **KESTREL** actuator board, and ingesting actuator status. The protocol is
already defined in [`AppDrivers/CAN/CAN.h`](AppDrivers.md#can--). Implementing this is what
turns single-board actuation into the distributed
sensing-node ↔ actuation-node design
([SYSTEM_OVERVIEW §8 (Tier 3)](SYSTEM_OVERVIEW.md#8-the-control-and-actuation-path)).
Resolve the enum collision ([C8](CONCURRENCY_SAFETY.md#-c8--duplicate-enum-definitions-collide-across-headers))
first.

---

## At-a-glance status

| Module | Status |
|---|---|
| flight_sensors | ✅ |
| kalman | ✅ (dt now dynamic; Q/R still fixed) |
| pyro | ✅ (C1 blocking) |
| Lora_App | ✅ 🟡 (C3, C8) |
| packets (serializers) | ✅ 🟢 (N3 nit) |
| W25Q128_HAL | ✅ |
| crc16 | ✅ |
| flight_state / flight_config | 🟡 (M3 dead-end; refactor → FSM_DISPATCH_TABLE.md) |
| ControlLoop/airbrake | ❌ removed (staged) — control on KESTREL |
| CANTasks | 🧩 planned (stays on ODIN) |

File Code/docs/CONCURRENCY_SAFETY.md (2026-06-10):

# Concurrency, Memory-Safety & Atomicity — Refactor Notes

> **What this is.** A working list of where the firmware shares state, where it can
> block or hang, and where it is not memory-safe — plus the order I'd fix it in. It's
> written to be actionable: each finding has a **location**, **why it matters**, and a
> **fix**. No code is changed by this document.
>
> **Read the model first.** Today the system is a **single-context superloop** (`main.c`)
> with **one interrupt** (LoRa DIO0 → `EXTI9_5`). That means most "concurrency" bugs are
> *latent* — they don't bite while everything runs sequentially, but they will the moment
> you add an RTOS task, a DMA completion handler, or a second interrupt (e.g. a control
> loop or CAN RX). The findings below mark which are **active now** vs **latent**.
>
> **🔄 Re-review (current working tree).** Since the first pass: **M1** and **R2** are
> fixed, the per-pass hot-loop `printf` is gone, and the `ControlLoop/airbrake` stubs are
> staged for deletion. New code added a LoRa **RX command path** and a **continuity
> broadcast** (`telemetry.c`) plus a `packets.c/.h` serialization module — which introduce
> findings **N1–N3** below. Everything else (C1–C8, M3, R3, R4) still stands.
>
> **🔄 Audit #3 (commit `f925c21`).** That commit fixed the **in-flight** sensor reads
> (timeouts added to `lsm6dso_ExternalReader` 50 ms, `h3lis331dl_externalRead` 50 ms,
> `BMP388_ReadRawPressTempTime` 250 ms, IMU reset 100 ms) and cut the RX timeout 1000→50 ms
> (**N1** mitigated). The C4 fix intentionally left the two **calibration** loops
> (`lsm6dso_Calib`, `h3lis331dl_Calibration`) unbounded — **accepted** as a pre-flight
> fail-stop (see C4). New
> this pass: **N4** (LoRa TX/RX mode handling) and **NR1** (a BMP388 sensortime regression).

---

## Severity & status at a glance

**✅ Resolved / mitigated:** **M1** (`buff[62]`), **R2** (dynamic `dt`), **C4 in-flight reads**
(timeouts), **N1** (RX 50 ms). **Audit #4 (commits `cecc113`, `7d3d9f5` + working tree) adds:**
**C1** — pyro is now non-blocking via `pyro_service()` (timestamp deassert, `HAL_Delay` gone);
**M3** — low-apogee path now fires drogue+main then → `STATE_PARAFOIL` (no dead-end); **C5** —
`platform_*` now deassert CS and return an error code on SPI failure; **R4** — `Error_Handler`
now safes the pyro GPIOs; and the FSM debounce counters moved into `FSM_Context_t` (no more
switch-case statics). *(The C1/C5/M3/R4 detail sections further down describe the original
problem and are now historical.)* 🎉

> ✅ **Both now fixed in commit `b545bfd`** (verified): **P1** — the drogue typo is gone
> (`pyro.c` uses `drogue_fire_start` consistently; no `drouge` left anywhere, and the pin
> defines / `ContinuityPacket` field all align); **R1** — that same commit gated the main-loop
> sensor `printf`s behind `#ifdef DEBUG` (with `(void)` casts) and removed the per-RX prints in
> `lora_rx_command`. *(Heads-up: `b545bfd`'s message says "rename," but it also bundled these
> `printf`/`(void)` changes — worth splitting commits like that for traceability.)*

| ID | Finding | Severity | Active now? |
|----|---|---|---|
| **P1** | ✅ Fixed (`b545bfd`) — `pyro_fire_drogue` now uses `drogue_fire_start`; drogue deasserts in `pyro_service` | 🟢 Resolved | — |
| **C2** | `lora_TX` busy-polls (≤500 ms tx / ≤100 ms continuity) — still blocks the loop | 🟠 High | **Yes** |
| **R3** | No independent watchdog to recover from a hang | 🟠 High | **Yes** |
| **C1** | ✅ Fixed — `pyro_fire_*` non-blocking via `pyro_service()` *(but see **P1** for the drogue path)* | 🟢 Resolved | — |
| **C5** | ✅ Fixed — `platform_*` deassert CS + return non-zero on SPI error | 🟢 Resolved | — |
| **M3** | ✅ Fixed — low-apogee fires drogue+main → `STATE_PARAFOIL` (no dead-end) | 🟢 Resolved | — |
| **R4** | ✅ Improved — `Error_Handler` safes pyro GPIOs before `__disable_irq()` (still `while(1)`, no reset) | 🟢 Mostly | Minor |
| **C4** | In-flight reads time out ✅. Calibration loops block at boot — **accepted** (pre-flight fail-stop) | 🟢 Accepted | Boot only |
| **N1** | `lora_rx_command` RX poll 50 ms ✅ — still a blocking poll + `printf` | 🟢 Low | Yes (minor) |
| **N2** | Remote `CMD_FIRE` now hits `pyro_fire_*` state guards — but the command path **enables test-mode to bypass them** for ground pops; remote fire still doesn't set the FSM fired-flags | 🟡 Medium | By design |
| **C3** | `lora_tx_done_flag` now cleared before TX but still never *read* (TX still polls); prototype still misspelled | 🟡 Medium | Yes (waste) |
| **C8** | Duplicate `IDLE/ARMED…` enums in `CAN.h` & `Lora_App.h` → won't compile together | 🟡 Medium | Latent |
| **N4** | LoRa TX/RX error out unless already in STANDBY and don't restore it on timeout → rides on chip auto-timeout + loop timing | 🟡 Medium | Latent |
| **R1** | ✅ Largely fixed (`b545bfd`) — main-loop + FSM + RX `printf`s gated/removed. Remaining bare prints are debug-only callers / manual tools (`serial_print`, `flash_dump_serial`) + one "CMD valid" line | 🟢 Low | Minor |
| **NR1** | BMP388 sensortime bytes parsed from the wrong registers (regression) | 🟢 Low | Yes (time unused) |
| **C6** | Shared `sensorData` blackboard has no snapshot/atomicity | 🟡 Medium | Latent |
| **C7** | SPI1 shared by 3 sensors with no arbitration | 🟢 Low | Latent |
| **N3** | `CommandPacket` struct layout disagrees with `command_deserializer` wire offsets | 🟢 Low | Yes (footgun) |
| **M2** | serializers (`packets.c`) have an implicit, unchecked length contract | 🟢 Low | Yes (footgun) |

🔴 fix before next flight · 🟠 fix before adding concurrency/control · 🟡 fix soon · 🟢 cleanup

---

## Memory safety

### 🔴 M1 — Stack buffer overflow in `lora_tx_telemetry`
> **✅ RESOLVED in the current code** — `lora_tx_telemetry` now declares `uint8_t buff[62]`
> (`telemetry.c:37`) and the +4 offset is intentional (the receiver consumes the first 4
> bytes; the 58-byte payload starts at byte 4 → fits exactly in 62). Analysis kept below
> for reference. *(Apply the same care to the new `lora_tx_continuity`/`lora_rx_command`
> buffers — they currently fit: 8-byte continuity in `buff[12]`, 9-byte command in `buff[13]`.)*

**Location:** `Core/App/Outputs/Telemetry/telemetry.c:31-58`

```c
uint8_t buff[58] = {0};                    // 58 bytes: valid indices 0..57
...
telemetry_serializer(&packet, buff + 4);   // writes 58 bytes starting at +4  → buff[4..61]
result = lora_TX(buff, 62, 1000);          // sends 62 bytes               → reads buff[0..61]
```

`telemetry_serializer` always writes a fixed **58-byte** frame relative to the pointer it
is given (`Lora_App.c:44-180`, last write is `buff[57]`). Called with `buff + 4`, it
writes `buff[4]…buff[61]` — **4 bytes past the end** of a 58-byte array. Then `lora_TX`
is told the length is **62**, so it also **reads 4 bytes past the end**. This is a real
stack overwrite/over-read, not a style nit.

Note the comment *"LoRa driver consumes first 4 bytes internally"* is **not true** of the
current `lora_TX` — it writes all `length` bytes from `data[0]` into the FIFO. So the
4-byte pad is also transmitted, shifting the real payload.

**Why it matters:** corrupts whatever sits above `buff` on the stack; behavior depends on
the compiler's stack layout, so it can look fine on the bench and fault in flight. It also
means the last 4 telemetry bytes on the wire are garbage.

**Fix:** make the buffer big enough and make the offset intentional. Either size it to the
real on-wire length (`uint8_t buff[62]` if you genuinely want a 4-byte pad, then send 62)
or drop the `+4` and send 58. Decide what the 4 bytes are *for* (FIFO base address? sync
preamble?) and document it. Cross-check against the flash path, which is correct:
`flash_log_telemetry` uses `buff[64]` and serializes at offset 0 (`telemetry.c:60-76`).

### 🟢 M2 — `telemetry_serializer` has an implicit length contract
**Location:** `Core/App/ApplicationLayer/ApplicationHALS/Lora_App.c:44`

The serializer takes only `(packet, buff)` — no length — and unconditionally writes 58
bytes. The caller must *just know* to pass ≥58 bytes from the pointer. That implicit
contract is exactly what made **M1** possible.

**Fix:** pass the destination length and bounds-check (`telemetry_serializer(packet, buff,
buflen)` returning bytes written, or `static_assert`/comment the required size at every
call site). Cheap insurance against the next caller.

### 🟠 M3 — Low-apogee deploy leaves the FSM stuck in `DROGUE`
**Location:** `Core/App/ApplicationLayer/FlightStateMachine/flight_state.c:121-159`

At `APOGEE` entry the deploy logic branches on apogee altitude:

```c
if (ctx.apogee_alt < MAIN_DEPLOY_ALT_M) { pyro_fire_main();   ctx.main_fired = 1; }  // low-apogee contingency
else                                    { pyro_fire_drogue(); ctx.drogue_fired = 1; }
FSM_transition(STATE_DROGUE);
```

The low-apogee branch is **intentional and sensible** (per the author): if you're already
below the main-deploy altitude at apogee, there's no useful drogue-descent phase, so you
fire main immediately. The bug is the **transition target** — *both* branches go to
`STATE_DROGUE`, but every exit from `STATE_DROGUE` is gated on `main_fired != 1`
(`:148` and `:153`):

```c
if (alt < MAIN_DEPLOY_ALT_M && ctx.main_fired != 1) { ... FSM_transition(STATE_PARAFOIL); }
if (timeout                 && ctx.main_fired != 1) { ... FSM_transition(STATE_PARAFOIL); }
```

In the low-apogee case `main_fired` is already `1` on entry, so **neither exit can ever
fire** and the FSM is **permanently stuck in `DROGUE`**. The main chute still deploys —
this is a state-machine dead-end, not a deployment failure — but `PARAFOIL`/`LAND` are
never reached, so landing is never detected, any parafoil-deploy logic never runs, and
telemetry/logging report `DROGUE` for the rest of the flight. It triggers on a genuinely
low apogee *or* a baro/Kalman under-read at apogee, so fix it before any flight where a
sub-`MAIN_DEPLOY_ALT_M` apogee is possible (including a motor anomaly).

**Fix:** in the low-apogee branch, transition straight to `STATE_PARAFOIL` (post-main
descent) instead of `STATE_DROGUE`, so the normal landing watch takes over:

```c
if (ctx.apogee_alt < MAIN_DEPLOY_ALT_M) { pyro_fire_main();   ctx.main_fired = 1;   FSM_transition(STATE_PARAFOIL); }
else                                    { pyro_fire_drogue(); ctx.drogue_fired = 1; FSM_transition(STATE_DROGUE);   }
```

While here, consider centralizing deploy in one helper that refuses to re-fire a channel
whose flag is already set, so this path stays auditable. (See
[SYSTEM_OVERVIEW.md §6](SYSTEM_OVERVIEW.md#6-the-flight-state-machine).)

---

## Blocking calls (kill these before any control loop)

A closed-loop airbrake/fin controller needs a **fixed-rate, jitter-bounded** slot. Every
blocking call below injects latency into the one loop that would host it.

### 🔴 C4 — Unbounded sensor busy-waits with no timeout
> **🔄 Audit #3 — partially fixed.** The **in-flight read paths are now FIXED** (commit
> `f925c21`): `lsm6dso_ExternalReader` (50 ms), `h3lis331dl_externalRead` (50 ms),
> `BMP388_ReadRawPressTempTime` (250 ms), and the `lsm6dso_init` reset (100 ms) all time out
> and return `HAL_TIMEOUT`/`HAL_ERROR`. **Still unbounded — and they run at *boot* in
> `flight_sensors_init`:** `lsm6dso_Calib` (`lsm6dsox_hal.c:159-161`) and
> `h3lis331dl_Calibration` (`h3lis331dl_hal.c:154-156`); the latter also *lost* its
> `HAL_Delay(1)`, so it now spins the CPU. **Accepted by design (maintainer call):** these run
> only at boot in `flight_sensors_init`, so a dead/flaky sensor hangs *on the pad*, not in
> flight — and since no telemetry/continuity ever comes up, the ground crew sees the board
> never went "ready" and doesn't fly. That's a valid pre-flight fail-stop. It stays valid as
> long as (1) a hung board is **ground-observable** (no telemetry = stuck — true today) and
> (2) calibration/re-init never moves into the in-flight path. Restoring the dropped
> `HAL_Delay` / adding a deadline is nice-to-have (stops the CPU spin) but not flight-critical.

**Locations (the two calibration entries below are the ones still open):**
- `Core/App/AppDrivers/Sensors/lsm6dsox_hal.c:195-197` — `lsm6dso_ExternalReader`: `do { status_get } while(!xlda || !gda);` — **no delay, no timeout**.
- `Core/App/AppDrivers/Sensors/lsm6dsox_hal.c:58-60` — reset wait in `lsm6dso_init`: `do { reset_get } while (rst);`
- `Core/App/AppDrivers/Sensors/lsm6dsox_hal.c:156-158` — same pattern in `lsm6dso_Calib`.
- `Core/App/AppDrivers/Sensors/h3lis331dl_hal.c:134-137` and `157-160` — `do { delay(1); read } while(!(status & 0x08));`
- `Core/App/AppDrivers/Sensors/BMP388.c:244` — `do {…} while (!(status & …));`

**Why it matters:** if a sensor browns out, resets, or the SPI line glitches and
data-ready never asserts, these loops **never exit** — and because it's a superloop, the
*entire flight computer hangs*: no estimation, no FSM, no deploy, no telemetry. This is
the single most dangerous class of bug here. The IMU read is worst (no `HAL_Delay`, so it
also pins the CPU).

**Fix:** every wait gets a `HAL_GetTick()` deadline and returns `HAL_TIMEOUT` on expiry
(the flash driver already does this correctly — `W25Q128_WaitBusy`,
`Core/App/AppDrivers/Memory/W25Q128.c:43-52` — copy that pattern). Propagate the timeout
up so the caller can mark the sensor failed and continue on the remaining sensors. Pair
with **R3** (watchdog) as a backstop.

### 🔴 P1 — Drogue fire-timer variable typo (drogue channel never deasserts)
> **✅ RESOLVED in commit `b545bfd`** — the rename made `pyro.c` use `drogue_fire_start`
> consistently (declared `:13`, set `:63`, cleared in `pyro_service` `:83`), so the drogue line
> now deasserts after `PYRO_FIRE_DURATION_MS`. No `drouge` spelling remains anywhere (verified
> across `Core/`, `FATFS/`, and the `.ioc`), and the pin defines + `ContinuityPacket` field
> stayed aligned. Analysis kept below for reference.

**Location (original):** `Core/App/ApplicationLayer/ApplicationHALS/pyro.c` — `pyro_fire_drogue:62` vs the
declaration at `:13` and `pyro_service:82-84`.

The pyro refactor (good — see C1) deasserts each channel by timestamp in `pyro_service()`.
But `pyro_fire_drogue` writes the start time to **`drouge_fire_start`** (line 62), while the
only declared variable is **`drogue_fire_start`** (line 13) — which is what `pyro_service`
checks (line 82). The spellings differ ("drouge" vs "drogue"):

- If `drouge_fire_start` is undeclared, **the file does not compile** (the latest change may
  not have been rebuilt yet).
- If it *did* build, `pyro_service` watches `drogue_fire_start`, which `pyro_fire_drogue` never
  sets — so after a drogue fire the GPIO is asserted and **never deasserted**: the drogue
  igniter stays energized indefinitely.

Either way the drogue path is broken, it's safety-critical (a pyro channel), and it runs on
**every** apogee (both the normal and low-apogee branches call `pyro_fire_drogue`). **Fix:**
use one spelling everywhere (`drogue_fire_start`). Building with `-Wall -Werror` would have
caught this — worth enabling.

### 🟠 C1 — Pyro and buzzer block the loop with `HAL_Delay`
> **✅ RESOLVED (audit #4).** `pyro_fire_*` now assert the GPIO + record a timestamp, and
> `pyro_service()` (called each loop) deasserts after `PYRO_FIRE_DURATION_MS`; `HAL_Delay` is
> gone from `pyro.c`. **Caveat: the drogue path is broken by a typo — see P1.** (The buzzer
> `HAL_Delay` in `indicators.c` is unchanged, used only as a startup chirp.)

**Locations (original):** `Core/App/ApplicationLayer/ApplicationHALS/pyro.c:34-48`
(`pyro_fire_drogue/main/aux` each `HAL_Delay(500)`); `Core/App/Outputs/LED&buzzer/indicators.c:3-10`.

**Why it matters:** firing a pyro freezes the superloop for **500 ms** — during descent
that's 50 missed IMU samples, ~12 missed baro samples, no telemetry, no logging. At
`APOGEE`→`DROGUE` two fires can chain. For one-shot pyro it's *survivable*; for a
continuous control surface it is disqualifying.

**Fix:** make firing non-blocking — on fire, set the GPIO and record
`fire_start = HAL_GetTick()`; in the loop (or a timer ISR) clear it once
`HAL_GetTick() - fire_start >= PYRO_FIRE_DURATION_MS`. A hardware timer one-pulse is even
cleaner. Same treatment for the buzzer (state, not `HAL_Delay`).

### 🟠 C2 — `lora_TX` busy-polls up to 1 s
**Location:** `Core/App/AppDrivers/LoRa/LoRa.c:432-442` (called from
`lora_tx_telemetry`, `telemetry.c:51`, with a 1000 ms timeout).

```c
while (!(buffer & IRQ_TX_DONE_MASK)) {
    platform_read(&sx1, REG_IRQ_FLAGS, &buffer, 1);   // SPI read every spin
    if ((HAL_GetTick() - start) >= timeout_ms) return HAL_TIMEOUT;
}
```

**Why it matters:** the loop spins on SPI reads for the full packet airtime (and up to
1 s on failure), stalling everything. It also makes the radio and the (future) control
loop fight for time.

**Fix:** this is what the DIO0 interrupt is *for* — see **C3**. Drive TX completion off
the interrupt (or DMA + completion callback) and let the superloop/control task keep
running while the radio transmits.

---

## Interrupts & synchronization

### 🟡 C3 — LoRa TX-done interrupt is set up but never consumed
**Locations:** ISR `Core/App/ApplicationLayer/ApplicationHALS/Lora_App.c:11-15` sets
`lora_tx_done_flag = 1`; the flag (declared `Lora_App.c:9`) is **never read** anywhere in
the codebase, because `lora_TX` busy-polls instead (**C2**).

So the interrupt-driven completion path is fully wired (EXTI configured in
`MX_GPIO_Init`, handler in `stm32f4xx_it.c:205`) but dead. Two smaller issues ride along:

- **Prototype mismatch:** `Lora_App.h:63` declares `HAL_GPIOEXTI_Callback` (missing the
  underscore), but the implementation is the real HAL weak symbol
  `HAL_GPIO_EXTI_Callback`. The declared prototype is wrong *and* unused — delete or fix.
- If you do start reading the flag, treat it as the classic ISR-flag pattern: `volatile`
  (it is), **set in ISR, cleared by the consumer**, and don't do read-modify-write on it
  from both contexts.

**Fix:** consume the flag — clear it before starting TX, return to the loop, and check it
(or use `HAL_GPIO`/DMA TX-complete callbacks). This single change resolves **C2** as well.

### 🟡 C8 — Duplicate enum definitions collide across headers
**Locations:** `Core/App/AppDrivers/CAN/CAN.h:41-53` and
`Core/App/ApplicationLayer/ApplicationHALS/Lora_App.h:48-59` both define an enum with
`IDLE, ARMED, POWERED_ASCENT, …`.

**Why it matters:** including both headers in one `.c` is a **redefinition compile error**.
It hasn't bitten yet only because `CAN.c` is an empty stub. The moment you implement CAN
and a file needs both (very likely — CAN broadcasts FSM state *and* you serialize it for
LoRa), it won't build.

**Fix:** define the flight-state enum **once** (e.g., a shared `flight_state.h` or a new
`flight_ids.h`) and have both subsystems include it. Prefix enumerators
(`FS_IDLE`, `FS_ARMED`, …) to avoid polluting the global namespace. While there, note
these LoRa/CAN state codes are a *different numbering* from `FlightState_t` in
`flight_state.h` — make the mapping explicit and one-directional.

---

## Shared state & atomicity (the part that matters when you add concurrency)

Today there is effectively **one writer and one reader, in sequence**, so nothing below is
*corrupting* data right now. But this section is the core of "make it concurrency-safe and
atomic," because each item becomes a race the instant a second context appears.

### Inventory of shared mutable state

| State | Where | Written by | Read by |
|---|---|---|---|
| `FlightSensorData sensorData` | `main.c:93` (global) | main loop (sensor + KF updates) | FSM, telemetry, flash, KF |
| `KalmanFilter_t kf` | `kalman.c:5` (file static) | `kalman_predict/update` | `kalman_get_*` |
| `FSM_Context_t ctx` | `flight_state.c:9` (file static) | `FSM_update/transition` | `FSM_get_state` |
| `lora_tx_done_flag` | `Lora_App.c:9` (volatile) | **EXTI ISR** | (nobody — see C3) |
| `flash_write_addr`, `flash_record_count` | `W25Q128_HAL.c:9-10` | `flash_log_packet` | read path |
| per-driver `static stmdev_ctx_t dev_ctx`, cal offsets | sensor HALs | init | reads |
| `Timer1/Timer2` | `fatfs_sd.c:11` (volatile) | **SysTick ISR** (dec) | SD path (dead) |

### 🟡 C6 — The `sensorData` blackboard is not snapshot-safe
**Location:** `Core/Src/main.c:93`, passed by pointer everywhere.

`sensorData` is ~60 bytes of floats updated field-by-field across the loop, then handed by
pointer to `FSM_update`, `lora_tx_telemetry`, `flash_log_telemetry`. In the superloop the
writes complete before the reads, so reads are consistent. **Under concurrency** (a comms
or logging task, or reading it from an ISR) a reader can observe a *torn* struct — e.g.
new altitude with old velocity — because a multi-field struct copy is **not atomic** and
individual `float` writes aren't ordered.

**Fix — pick one:**
- **Double-buffer (ping-pong):** writer fills buffer B, then publishes by swapping an
  index/pointer (a single aligned 32-bit store *is* atomic on Cortex-M4). Readers grab the
  current pointer once and use it. Simple, lock-free, ideal for one-writer/many-readers.
- **Seqlock:** writer bumps a counter before/after writing; reader retries if the counter
  changed or is odd. Great for a high-rate producer and occasional readers.
- **Critical section:** wrap the copy in `__disable_irq()/__enable_irq()` (or
  `taskENTER_CRITICAL` under an RTOS). Easiest; costs a little latency.

The rule to adopt: **readers take an atomic snapshot, never walk the live struct.**

### 🟢 C7 — SPI1 is shared by three sensors with no arbitration
**Location:** all three sensor handles set `hspi = &hspi1` (`flight_sensors.c:34,48,61`);
each `platform_read/write` toggles only its own CS.

In the superloop, accesses are naturally serialized, so this is fine. If sensor reads ever
move to DMA, an ISR, or separate tasks, two transfers could interleave on the same bus and
on overlapping CS lines → corrupted reads.

**Fix (only when you go concurrent):** put a single **bus mutex** (or an SPI transaction
queue) around SPI1; acquire it for the whole CS-low→transfer→CS-high sequence. The radio
(SPI2) and flash (SPI3) are already isolated, so only SPI1 needs it.

### 🟠 C5 — SPI errors are silently swallowed
**Locations:** `lsm6dsox_hal.c:106-135` and `h3lis331dl_hal.c:94-122` — `platform_read`
and `platform_write` call `HAL_SPI_Transmit/Receive` but **discard the return value and
always `return 0`** (success).

**Why it matters:** a SPI timeout or bus error looks like a successful read of stale/zero
data. That zero then flows into the Kalman filter and FSM. It also defeats **C4**'s
timeout fix at the wrong layer (the ST `*_reg` layer checks this return code).

**Fix:** return a non-zero code on `HAL` failure so the ST driver and your wrappers can see
it; map it to `HAL_ERROR` at the `flight_sensors_*` boundary and mark the sensor failed.

---

## Real-time hygiene

### 🟡 R1 — `printf` in the hot loop
**Locations:** `main.c:211` prints every single pass; `:218,226` on errors; plus a
`printf` on every FSM state entry (`flight_state.c`) and many driver error paths.

`_write` (`main.c:101`) does a **blocking** `HAL_UART_Transmit(..., HAL_MAX_DELAY)` at
115200 baud (~87 µs/byte). A ~45-char line ≈ **4 ms** — longer than a whole 10 ms IMU
slot, and it's unbounded if the line is long. This is both a latency source and a jitter
source for any future control loop.

**Fix:** gate all hot-path prints behind `#ifdef DEBUG` (the loop already has a `DEBUG`
block — extend it), or move to a DMA/ring-buffer logger that never blocks the producer.
Definitely remove the unconditional per-pass `printf` at `main.c:211`.

### 🟡 R2 — Kalman `dt` is hard-coded
> **✅ RESOLVED in the current code** — `main.c:211` now computes
> `dt = (now - last_imu) / 1000.0f` and passes it to `kalman_predict`. One nit: the *first*
> predict uses time-since-boot as `dt`; `kalman_predict` rejects `dt > 1`, so a long init is
> safely ignored, but a sub-second init still yields one oversized first step — harmless,
> the covariance just re-converges.

**Location (original):** `main.c:219` — `kalman_predict(sensorData.z_mg_IMU, 0.01f);`

`dt` is fixed at 10 ms regardless of how long the pass actually took. Any jitter (from
C1/C2/R1) means the filter integrates over the wrong interval, biasing velocity/altitude.

**Fix:** measure real elapsed time between predicts (`now - last_imu` in seconds) and pass
that. `kalman_predict` already validates `0 < dt ≤ 1`.

### 🟠 R3 — No independent watchdog
**Observation:** no IWDG/WWDG is started. Given **C4**, a single stuck sensor read is an
unrecoverable brick.

**Fix:** enable the independent watchdog (IWDG) and kick it once per healthy loop pass, so
a hang reboots the MCU instead of freezing forever.

> ⚠️ **A watchdog is a backstop, not the primary fix — and a naive reset is dangerous in
> flight.** On reboot, `FSM_init()` resets the state to `IDLE` (`flight_state.c:13-17`), so
> a watchdog reset mid-flight would **lose the entire flight state** — the vehicle could
> re-arm, re-run launch detection, and mis-time recovery. So:
> 1. **Primary fix is C4** — bounded timeouts on every poll, so one bad sensor *degrades
>    gracefully* (skip it, flag it, keep flying on the others) instead of hanging at all.
>    The watchdog should almost never fire.
> 2. If you keep the IWDG (you should), make the reset **recoverable**: persist flight
>    state + key estimator values to **RTC backup registers** or **backup SRAM** (which
>    survive a reset) and restore them on boot, or boot into a dedicated "in-flight
>    recovery" state — never silently back to `IDLE`.
> 3. On boot, verify pyros are in the safe (low) state before doing anything else.

### 🟡 R4 — Fault handlers brick silently
**Locations:** `Error_Handler` (`main.c:761`, `__disable_irq(); while(1){}`), and
`HardFault/MemManage/BusFault/UsageFault_Handler` (`stm32f4xx_it.c:84-139`) all spin
forever.

**Why it matters:** a fault in flight leaves pyros in whatever state they were in, radio
silent, with interrupts off.

**Fix:** in the fault path, first drive all igniter GPIOs low (reuse `pyro_init`'s safe
state), optionally emit a last-gasp telemetry/flash marker, then reset via `NVIC_SystemReset()`
so the watchdog/boot can recover.

---

## New findings (RX / command / continuity paths)

From the new `lora_rx_command` / `lora_tx_continuity` code in `telemetry.c` and the
`packets.c/.h` module.

### 🟠 N1 — `lora_rx_command` blocks the loop up to 1 second
**Location:** `Core/App/Outputs/Telemetry/telemetry.c:137-186`, called from `main.c:241`.

At `STATE_PAD`, after each telemetry TX the loop calls `lora_rx_command()`, which does
`lora_RX(buff, &rxLength, 13, 1000)` — a **busy-poll with a 1000 ms timeout** (same polling
style as `lora_TX`). If no command arrives, the loop stalls for up to a full second: no
sensor reads, no Kalman update, no FSM tick. It also `printf`s on *every* call (including
timeouts) plus a 13-byte hex dump on receipt — more blocking UART in the path.

**Why it matters now:** it's only wired at PAD (pre-launch), so it won't stall an in-flight
loop — but it makes launch detection laggy, and it's exactly the kind of blocking call that
must go before this loop hosts anything time-critical. Same root cause as **C2/C3**: polling
instead of using the DIO0 RX-done interrupt.

**Fix:** drop the RX timeout to the minimum that catches a command between telemetry frames
(tens of ms), or — better — make RX interrupt/DMA-driven (DIO0 RX-done → flag → drain), and
gate the `printf` behind `DEBUG`.

### 🟡 N2 — Remote `CMD_FIRE` bypasses the FSM deploy flags and state guard
**Location:** `Core/App/Outputs/Telemetry/telemetry.c:160-178`.

A valid `CMD_FIRE` calls `pyro_fire_drogue()` / `pyro_fire_main()` directly. Issues:
- It does **not** set `ctx.main_fired` / `ctx.drogue_fired`, so the FSM has no record a
  channel fired. If the autonomous FSM later reaches APOGEE/DROGUE it can fire the *same*
  channel again — the two fire paths share no interlock.
- It's gated only by *where it's called* (main.c calls `lora_rx_command` only at
  `STATE_PAD`), not by a check inside the handler. Fragile — if the call site ever moves, a
  ground command could fire pyros in flight.
- The fire itself is the 500 ms blocking `HAL_Delay` (**C1**), now inside the RX handler.

The command *authentication* is good (sync + `command_packet` type + `0xBE` auth byte +
CRC16 in `command_deserializer`, `packets.c:159`); this is about the command's *effect*, not
its validation.

**Fix:** route manual fire through the **same single deploy helper the FSM uses** (the one
suggested in **M3**) so it sets/honors the fired flags and refuses to re-fire, and add an
explicit allowed-state check inside the handler instead of relying on the call site.

### 🟢 N3 — `CommandPacket` struct disagrees with the deserializer's wire layout
**Location:** `packets.h:47-53` vs `command_deserializer` (`packets.c:159-174`).

The `CommandPacket` struct implies `[sync, type, seq, cmd_id, channel, auth, crc]` (auth at
byte 5). But the deserializer reads `cmd_id` at `buff[3]`, `channel` at `buff[4]`, **`auth`
at `buff[6]`**, CRC at `buff[7..8]` — i.e. a 9-byte frame with an unused byte at `buff[5]`.
The struct and the on-wire format the parser enforces don't match, and there's no
`command_serializer` in this repo to pin it down (the ground station defines the other end).

**Why it matters:** whoever writes the ground-station command frame must match the
*deserializer*, not the struct — easy to get wrong, and a mismatch silently fails CRC
(command ignored). Also `ContinuityPacket.aux` exists but `continuity_serializer` hardcodes
that byte to `0x00` (`packets.c:150`) — aux continuity isn't actually transmitted.

**Fix:** document the exact command wire format in one place (ideally add a matching
`command_serializer`, even if only the ground station uses it) and reconcile the struct
field order with the byte offsets the deserializer uses.

### 🟡 N4 — LoRa TX/RX are order-dependent on radio mode (no forced standby)
**Location:** `Core/App/AppDrivers/LoRa/LoRa.c` — `lora_TX:406`, `lora_RX:462`, and the
timeout/error early-returns in both.

Both `lora_TX` and `lora_RX` start with `if (mode != MODE_STAND_BY) return HAL_ERROR` — they
*assume* the caller left the radio in standby rather than forcing it. Their timeout / CRC /
SPI-error early-returns also leave the radio in `TRANSMIT` / `RX_SINGLE`, not standby. The new
code now **interleaves TX (telemetry/continuity) and RX (command) in the main loop**, so the
radio's mode is shared state across calls.

Concretely: `lora_rx_command` calls `lora_RX(..., 50 ms)`. `REG_SYMB_TIMEOUT` is never set, so
RX_SINGLE uses the chip default (~100 symbols ≈ 100 ms at SF7/BW125). The 50 ms driver poll
expires *first*, so on the normal "no command" path `lora_RX` returns `HAL_TIMEOUT` with the
radio **still in RX_SINGLE**. It recovers only because (a) the SX1276 auto-returns to standby
when its own symbol-timeout fires ~50 ms later, and (b) the next TX is ~200 ms away. So it
works today **by timing coincidence, not by design**: shorten the telemetry interval below
~100 ms, or TX right after RX, and that next TX would hit the standby check and silently fail
(dropped frame).

**Fix:** make the mode explicit — call `lora_standby()` at the *start* of `lora_TX`/`lora_RX`
(force a known mode instead of erroring out), and drive the radio back to standby on every
timeout/error exit. Setting `REG_SYMB_TIMEOUT` to a defined value also makes RX_SINGLE
deterministic.

### 🟢 NR1 — BMP388 sensortime parsed from the wrong registers (regression in `f925c21`)
**Location:** `Core/App/AppDrivers/Sensors/BMP388.c` — the `*time` assignment in
`BMP388_ReadRawPressTempTime`.

The commit changed the sensortime parse from `raw_data[10/9/8]` to `raw_data[8/7/6]`. The
11-byte burst starts at `DATA_0` (0x04), so `SENSORTIME_0..2` (0x0C–0x0E) are indices
**8, 9, 10** — the original was correct; indices 6/7/8 read `0x0A/0x0B/0x0C` (wrong registers).
Pressure (idx 0–2) and temperature (idx 3–5) are unchanged and still correct, and `time` isn't
consumed downstream, so this is **harmless today** — but it's a latent correctness bug if you
ever use sensor time. **Fix:** restore `*time = raw_data[10]<<16 | raw_data[9]<<8 | raw_data[8]`.

---

## Target architecture for "concurrency-safe and atomic"

Two viable paths. **You don't need an RTOS to be safe** — but you do need to stop blocking.

> **Recommendation for ODIN V2: Path A (non-blocking superloop + DMA + IWDG), not an RTOS.**
> DMA and RTOS aren't alternatives — DMA is *how peripherals move data*, an RTOS is *how
> you schedule tasks*; you can use both. But the decision is about workload. Now that
> active control is offloaded to the KESTREL board, ODIN's job is a fixed set of **periodic**
> tasks (sense → estimate → decide → log → downlink). That is the ideal case for a
> **time-triggered / cyclic-executive superloop**: it's more deterministic and far easier
> to verify than a preemptive RTOS, with no context-switch jitter, no per-task stacks, and
> none of the concurrency hazards in this very document. Add **DMA + interrupts** for the
> SPI sensor reads and the LoRa radio so the CPU stops busy-waiting (kills C1/C2/C4), and
> **IWDG** as the backstop. Reach for an RTOS only when you genuinely have many
> asynchronous, mixed-priority, event-driven tasks (multiple comms links, command shells,
> a filesystem) — not the case here. *(On KESTREL the calculus is similar; if its control
> loop must share the CPU with heavy CAN traffic and needs a guaranteed hard-real-time
> slot, a small RTOS or cyclic executive there is more defensible — but DMA + non-blocking
> is usually still enough.)*

### Path A — Stay superloop, go fully non-blocking (recommended next step)
Lowest risk, keeps determinism, unblocks a control loop:
1. Replace every blocking wait with a bounded, non-blocking state machine: pyro fire by
   timestamp (**C1**), sensor reads with timeout (**C4**), LoRa TX off the DIO0 interrupt
   (**C2/C3**), logging via a ring buffer drained incrementally.
2. Convert SPI to **DMA + completion flag** so reads/writes overlap compute.
3. Keep the single writer; publish `sensorData` via **double-buffer** (**C6**) so any ISR
   or DMA callback reads a consistent snapshot.
4. The freed-up determinism directly benefits ODIN's estimation and telemetry timing — and
   the same non-blocking pattern is exactly what KESTREL's control loop should follow so it
   runs at a fixed, jitter-bounded rate.

### Path B — Move to an RTOS (FreeRTOS / CMSIS-RTOS) when complexity grows
Adopt when you have several independent rates (control + comms + logging + CAN):
- **Tasks:** `sensor+estimate` (highest prio, hard 100 Hz), `control` (fixed rate),
  `comms/telemetry` (lower), `logging` (lowest). 
- **ISRs do the minimum:** set a flag / give a semaphore / push to a queue, then return.
- **Share state by message-passing** (queues) where possible; where you must share memory,
  use a **mutex** (with priority inheritance) or the **double-buffer/seqlock** patterns
  above. One **SPI1 bus mutex** (**C7**).
- Size each task's stack from worst-case; keep **static allocation**
  (`xTaskCreateStatic`) to preserve the no-heap property.

### The atomicity rules to adopt either way
- **One writer per piece of state.** Many readers are fine; many writers need a lock.
- **Readers take a snapshot** (double-buffer/seqlock/critical section) — never read a
  live multi-field struct that an ISR/other task can be mid-write on.
- **ISRs only signal** (set `volatile` flag, give semaphore, enqueue). No business logic,
  no blocking, no long SPI transactions in an ISR.
- **Every wait is bounded** by a timeout, and a watchdog backs the whole thing.
- A single aligned ≤32-bit load/store *is* atomic on Cortex-M4; anything wider or any
  read-modify-write across contexts needs protection (`__disable_irq`/PRIMASK, LDREX/STREX,
  or an RTOS primitive).

---

## Suggested order of work

*(Done: **M1**, **R2**, **C4 for the in-flight reads**, **N1** mitigated.)*

1. **C5** — stop swallowing SPI errors (`platform_*` should return the HAL status, not always 0). 🔴
   *(C4's calibration-loop hang is **accepted** as a pre-flight fail-stop — see C4; no action.)*
2. **M3** — fix the low-apogee FSM dead-end (`APOGEE` low branch → `PARAFOIL`, not `DROGUE`). 🔴/🟠
3. **R3** — turn on the IWDG watchdog as a safety net behind #1. 🟠
4. **C1 + N2** — non-blocking pyro fire; route remote `CMD_FIRE` through the same guarded
   deploy helper (sets fired-flags, state-checked). 🟠
5. **C2 + C3 + N4** — interrupt/DMA-driven LoRa TX *and* RX; consume `lora_tx_done_flag`;
   force radio standby on entry/exit so TX and RX can't wedge each other. 🟠
6. **R1** — gate the remaining `printf` (error paths, FSM transitions, RX handler) behind `DEBUG`. 🟡
7. **C8 + N3 + NR1** — unify the duplicate flight-state enums before CAN; pin down the command
   wire format; restore the BMP388 sensortime bytes. 🟡/🟢
8. **C6 + C7** — double-buffer `sensorData` and add an SPI1 mutex *as part of* going
   concurrent / adding a control task. 🟡/🟢
9. **R4** — safe-state fault handlers (drive pyros low, then reset). 🟡

Items 1–3 are "before next flight." Items 4–5 are "before active control." 6–9 ride along
with the concurrency/control work.

---

*Cross-references use the IDs above and match the call-outs in
[SYSTEM_OVERVIEW.md](SYSTEM_OVERVIEW.md). Line numbers are from the `dev` branch at
documentation time — re-verify after edits.*

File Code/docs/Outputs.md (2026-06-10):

# Outputs — Telemetry, Logging & Indicators

`Core/App/Outputs/`

Everything that leaves the board or surfaces state to a human: the LoRa downlink, the
onboard flash log, and the buzzer/LED. These modules sit at the top of the stack — they
*read* the `sensorData` blackboard and push it outward.

```
Outputs/
├── Telemetry/    telemetry.c   — serialize + downlink + flash-log + post-flight dump   ✅ 🟡
├── DataLogger/   logger.c      — 🧩 empty stub (logging actually lives in Telemetry)
└── LED&buzzer/   indicators.c  — buzzer beep helper                                     ✅
```

> **Heads-up on organization.** The naming suggests logging lives in `DataLogger/`, but it
> doesn't — `DataLogger/logger.c` is an empty stub, and the actual data-logging code is in
> `Telemetry/telemetry.c` (`flash_log_telemetry`) on top of
> [`W25Q128_HAL`](ApplicationLayer.md#w25q128_hal--flash-logging-policy-). Telemetry also
> reaches *down* to `Lora_App`'s serializer and the LoRa driver. It's a slight layering
> blur worth knowing when you go looking for the logging code.

---

## Telemetry/

### telemetry — downlink, logging, and replay ✅ 🟡
**Files:** `Telemetry/telemetry.c` (.h).

The single hub that builds telemetry frames and sends them to the radio, the flash, or the
console. Frames use the 58-byte format produced by
[`telemetry_serializer`](ApplicationLayer.md#lora_app--radio-config--telemetry-serialization-) (big-endian, CRC16).

| Function | Purpose | Notes |
|---|---|---|
| `serial_print(sensorData)` | Human-readable dump over UART (debug) | Blocking UART; keep behind `DEBUG` ([R1](CONCURRENCY_SAFETY.md#-r1--printf-in-the-hot-loop)) |
| `lora_tx_telemetry(sensorData)` | Build a packet, serialize, transmit over LoRa (5 Hz, state ≥ PAD) | ✅ `buff[62]` now (M1 fixed) |
| `lora_tx_continuity()` | Broadcast pyro continuity (main/drogue) every 2 s pre-launch (state ≤ PAD) | 12-byte packet, fits `buff[12]` |
| `lora_rx_command()` | Poll for an authenticated ground command at PAD; dispatch ARM/FIRE/DISARM | ⚠️ blocks ≤1 s + remote FIRE bypasses FSM flags ([N1](CONCURRENCY_SAFETY.md#-n1--lora_rx_command-blocks-the-loop-up-to-1-second)/[N2](CONCURRENCY_SAFETY.md#-n2--remote-cmd_fire-bypasses-the-fsm-deploy-flags-and-state-guard)) |
| `flash_log_telemetry(sensorData)` | Build a packet, serialize, append a 64-byte record to flash (25 Hz, state ≥ PAD) | ✅ correct buffer sizing |
| `flash_dump_serial()` | Read every flash record back and print decoded fields over UART | Post-flight analysis tool |

**Telemetry vs. logging — same data, two sinks, two rates:** the downlink runs at 5 Hz
(bandwidth-limited radio) while flash logging runs at 25 Hz (full-resolution post-flight
record). Both are gated to `state ≥ PAD` so the log isn't filled with idle pad data.

> ✅ **The earlier `lora_tx_telemetry` buffer overflow (M1) is fixed** — `buff[62]` now holds
> the 4-byte receiver header + 58-byte payload. The new `lora_tx_continuity` (12 B) and
> `lora_rx_command` (13 B) buffers are also correctly sized. See
> [CONCURRENCY_SAFETY M1](CONCURRENCY_SAFETY.md#-m1--stack-buffer-overflow-in-lora_tx_telemetry).
> The remaining hazards in this path are **N1** (RX blocks ≤1 s) and **N2** (remote FIRE
> bypasses the FSM flags).

**`flash_dump_serial` decoding** mirrors the serializer layout by hand
(`memcpy` of each float at its byte offset). If you ever change the wire format, you must
update *three* places in lockstep: the serializer, this decoder, and the ground-station
parser. Centralizing the field layout (a shared struct/offset table) would remove that
triple-maintenance hazard — related to
[M2](CONCURRENCY_SAFETY.md#-m2--telemetry_serializer-has-an-implicit-length-contract).

---

## DataLogger/  🧩

**Files:** `DataLogger/logger.c` (.h) — **empty stubs.**

Reserved for a dedicated logging module, but unused today; the live logging path is
`flash_log_telemetry` (above) + [`W25Q128_HAL`](ApplicationLayer.md#w25q128_hal--flash-logging-policy-).
If/when logging grows (multiple record types, a ring buffer, SD support), this is the
natural place to consolidate it — and a ring-buffered, non-blocking logger here is part of
the [Path A](CONCURRENCY_SAFETY.md#path-a--stay-superloop-go-fully-non-blocking-recommended-next-step)
non-blocking refactor.

---

## LED&buzzer/

### indicators — audible status ✅
**Files:** `LED&buzzer/indicators.c` (.h).

| Function | Purpose |
|---|---|
| `buzzer_function(time)` | Beep: buzzer on for `time` ms, off for `time` ms |

Minimal today. Two notes:
- `buzzer_function` uses **blocking `HAL_Delay`** twice
  ([C1](CONCURRENCY_SAFETY.md#-c1--pyro-and-buzzer-block-the-loop-with-hal_delay)) — fine
  for a startup chirp, not for use during flight.
- The **RGB LED** is wired to a **TIM2 PWM** pin (configured in `main.c`'s GPIO init) but
  nothing drives it yet — it's just a status indicator on this board. (Servo-driven control
  surfaces live on the KESTREL control board, not here — see
  [SYSTEM_OVERVIEW §8 (Tier 2)](SYSTEM_OVERVIEW.md#8-the-control-and-actuation-path).)
  Buzzer control is also duplicated in `pyro.c` (`pyro_buzzer_on/off`) — worth unifying so
  there's one owner of the buzzer GPIO.

---

## Data-out summary

| Sink | Module | Rate | Format | Status |
|---|---|---|---|---|
| LoRa downlink | `telemetry.c` → `Lora_App` → `LoRa.c` | 5 Hz (≥ PAD) | 58-byte CRC16 frame | ✅ 🟡 (M1) |
| Flash log | `telemetry.c` → `W25Q128_HAL` → `W25Q128.c` | 25 Hz (≥ PAD) | 64-byte records | ✅ |
| Console / replay | `serial_print`, `flash_dump_serial` | debug / on-demand | text | ✅ (keep behind DEBUG) |
| Buzzer | `indicators.c` / `pyro.c` | events | GPIO | ✅ (C1) |
| RGB LED | (TIM2 PWM configured) | — | PWM | 🧩 not driven |

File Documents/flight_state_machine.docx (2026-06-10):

Shingleback Flight State Machine

UTS Rocketry — Odin Flight Controller

Version 1.0 | AURC 2026

# Overview

The Shingleback flight computer uses an 8-state finite state machine to manage the full flight sequence from power-on through landing. All pyrotechnic events are gated behind multiple safety interlocks that check altitude, velocity, and acceleration before any charge can fire.

# States

## STATE_IDLE

The default power-on state. The system initialises all peripherals, runs sensor calibration, and waits for an arm command from the ground station over LoRa. Safe for bench testing — no pyro channels are active.

## STATE_PAD

The rocket is armed and sitting on the launch rail. The system continuously monitors the H3LIS331DL high-g accelerometer to detect launches. Pyro channels are armed in software but remain locked until the altitude interlock clears.

## STATE_BOOST

Motor is burning. The system logs all sensor data at the maximum rate. Pyro channels are hard-locked during this state — no ejection charges can fire, regardless of other conditions, while boost is active.

## STATE_COAST

The motor has burned out. The rocket is still climbing under momentum. The Kalman filter tracks vertical velocity — transition to apogee is triggered when the estimated vertical velocity crosses zero.

## STATE_APOGEE

Peak altitude reached. Drogue ejection charge fires. The system verifies the event via IMU settling before transitioning to the drogue state.

## STATE_DROGUE

Rocket is descending under drogue. The system monitors altitude using a Kalman filter and waits for the parafoil deployment altitude threshold to be reached.

## STATE_PARAFOIL

Parafoil is deployed. The CAS board takes control of the steering servos for guided descent. The system monitors altitude and accelerometer data to detect landing.

## STATE_LAND

Rocket has landed. The system transmits GPS position over LoRa at a reduced rate, activates the buzzer for recovery location, and logs final flight data to the SD card.

# Transition Conditions

From | To | Condition
STATE_IDLE | STATE_PAD | LoRa arm command received from the ground station
STATE_PAD | STATE_BOOST | H3LIS accel > LAUNCH_ACCEL_THRESHOLD (~3g)
STATE_BOOST | STATE_COAST | Accel drops back to ~1g (motor burnout)
STATE_COAST | STATE_APOGEE | Kalman estimated vertical velocity <= 0
STATE_APOGEE | STATE_DROGUE | Drogue charge fired + descent confirmed
STATE_DROGUE | STATE_PARAFOIL | Altitude < PARAFOIL_DEPLOY_ALT (300m AGL)
STATE_PARAFOIL | STATE_LAND | Altitude < LAND_ALT_THRESHOLD AND accel settled

# Pyro Safety Interlocks

Pyrotechnic channels are controlled by Pyro_SafeToFire(), which must return true before any charge can be triggered. ALL of the following conditions must be met simultaneously:

- Current state is NOT STATE_BOOST
- Altitude is above PYRO_ARM_ALT_THRESHOLD (100m AGL minimum)
- Vertical velocity is below MAX_SAFE_VEL
- Acceleration magnitude is below MAX_SAFE_ACCEL
- pyro_armed flag is set (only set in STATE_PAD and above)

The altitude interlock is the primary ground safety mechanism. Even if the software enters an unexpected state on the pad, no pyro channel can fire below 100m AGL. This protects the ground crew during preparation and on the launch rail.

bool Pyro_SafeToFire(void) {

if (current_state == STATE_BOOST) return false;

if (altitude < PYRO_ARM_ALT_THRESHOLD) return false; // 100m AGL

if (vertical_velocity > MAX_SAFE_VEL) return false;

if (accel_magnitude > MAX_SAFE_ACCEL) return false;

if (!pyro_armed) return false;

return true;

}

Parameter | Value | Notes
PYRO_ARM_ALT_THRESHOLD | 100.0 m AGL | Minimum altitude for any pyro event
MAX_SAFE_VEL | TBD m/s | Set after motor burn characterisation
MAX_SAFE_ACCEL | TBD g | Prevents firing under boost loads
pyro_armed | Set in PAD | Cleared on landing

# Configuration Constants

Defined in flight_state.h:

#define LAUNCH_ACCEL_THRESHOLD 3.0f // g — triggers PAD to BOOST

#define BURNOUT_ACCEL_THRESHOLD 1.5f // g — triggers BOOST to COAST

#define PYRO_ARM_ALT_THRESHOLD 100.0f // m AGL — minimum pyro arm altitude

#define PARAFOIL_DEPLOY_ALT 300.0f // m AGL — parafoil deployment

#define LAND_ALT_THRESHOLD 10.0f // m AGL — landing detection

#define LAND_ACCEL_SETTLE 0.1f // g variance — accel settle threshold

# Implementation Notes

- The state machine runs in the 10ms IMU task loop
- State is stored as a global FlightState_t current_state
- All state transitions are logged to the SD card with a timestamp
- The ground station receives the current state via LoRa telemetry every 200ms
- STATE_IDLE to STATE_PAD is the only transition triggered by LoRa — all others are sensor-driven
- The Kalman filter altitude and velocity estimates are used for all flight phase decisions

# Files

File | Purpose
App/ApplicationLayer/FlightStateMachine/flight_state.h | State enum, constants, declarations
App/ApplicationLayer/FlightStateMachine/flight_state.c | State machine logic, transitions
App/ApplicationLayer/ControlLoop/kalman.h/.c | Kalman filter for altitude/velocity
App/AppDrivers/LoRa/LoRa.h/.c | LoRa arm command parsing

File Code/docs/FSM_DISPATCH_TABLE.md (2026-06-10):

# FSM Refactor — Function-Pointer Dispatch Table

> **Goal.** Replace the monolithic `switch(ctx.state)` in `flight_state.c` with a
> **table of function pointers** indexed by the state enum. This document is design
> guidance and pointers only — **no code**. It maps your *current* 8-state FSM onto the
> pattern, calls out the gotchas that bite people, and gives an incremental migration plan.
>
> Files in scope: `Core/App/ApplicationLayer/FlightStateMachine/flight_state.c` / `.h`.

---

## 1. Why move off the switch

Your current `FSM_update()` is one `switch` with eight `case` blocks, each repeating the
same `if (ctx.entry) { ctx.entry = 0; ... }` preamble and calling `FSM_transition()` inline.
It works, but:

- **Every state's logic lives in one growing function** — hard to read, hard to test in
  isolation, easy to fall through a missing `break`.
- **Entry logic is copy-pasted** eight times.
- **Per-state counters** (`launch_count`, `burnout_count`, `apogee_count`) are `static`
  locals scattered in the cases — and they are **not reset by `FSM_init()`** (see §6, this
  is a latent bug today).
- **Transitions are scattered**, so the "what happens on a transition" bookkeeping is
  duplicated.

A dispatch table fixes all of that: each state becomes its own small, testable function;
entry/exit/transition bookkeeping is centralized; and adding or reordering states is a
one-line table edit.
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

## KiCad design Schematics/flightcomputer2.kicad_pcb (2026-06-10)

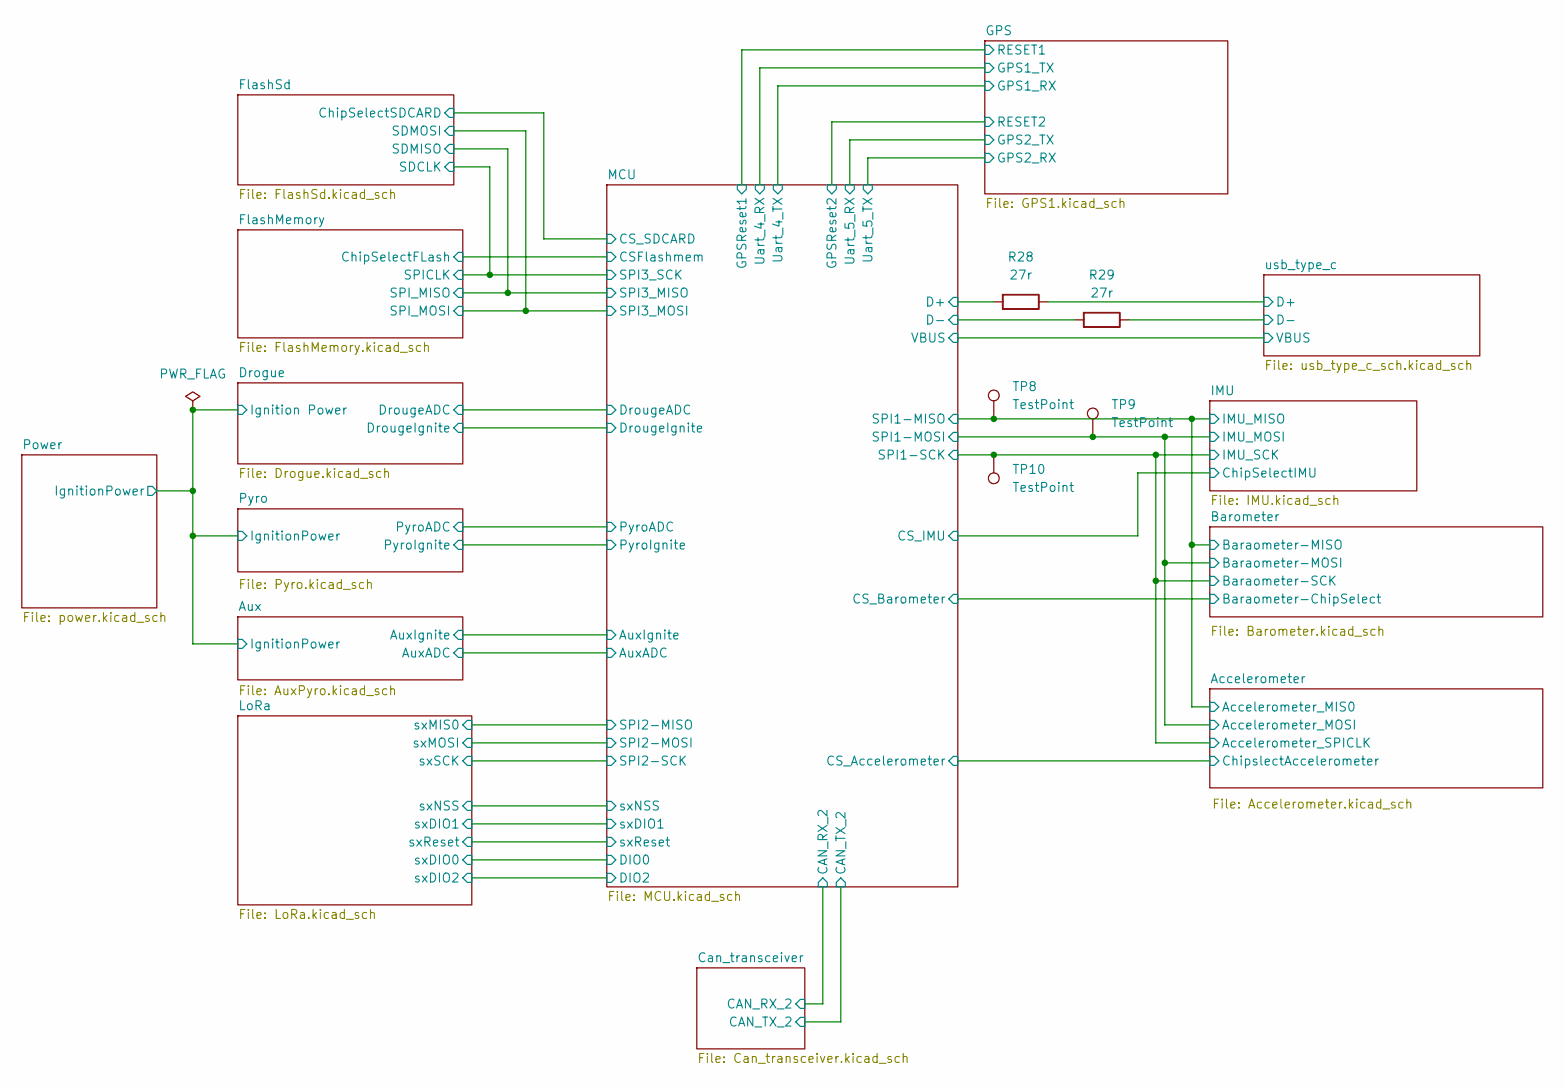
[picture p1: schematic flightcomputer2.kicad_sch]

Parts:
R28, R29: 27r; R_0805_2012Metric_Pad1.20x1.40mm_HandSolder
TP8, TP9, TP10: TestPoint; TestPoint_Pad_1.5x1.5mm

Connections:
/Accelerometer/Accelerometer_MIS0: TP8.1 (1_1); also elsewhere on the board
/Accelerometer/Accelerometer_MOSI: TP9.1 (1_1); also elsewhere on the board
/Accelerometer/Accelerometer_SPICLK: TP10.1 (1_1); also elsewhere on the board
/MCU/D+: R28.2; also elsewhere on the board
/MCU/D-: R29.2; also elsewhere on the board
/usb_type_c/D+: R28.1; also elsewhere on the board
/usb_type_c/D-: R29.1; also elsewhere on the board

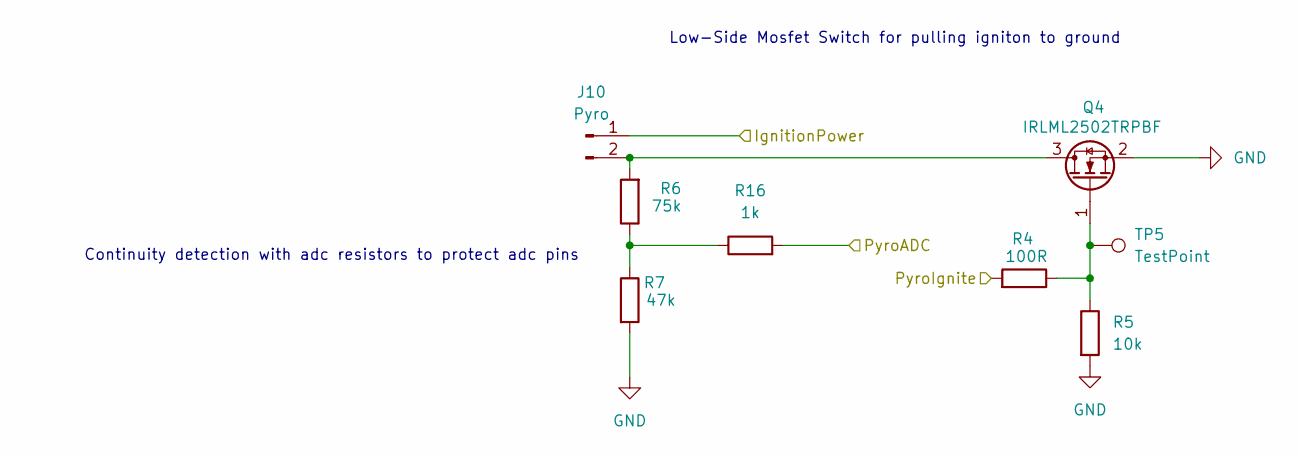
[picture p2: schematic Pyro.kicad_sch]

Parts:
J10: Pyro; MOLEX_26013114; LCSC C17644051
Q4: IRLML2502TRPBF; SOT23; LCSC C2589
R4: 100R; R_0805_2012Metric_Pad1.20x1.40mm_HandSolder; LCSC C17408
R5: 10k; R_0805_2012Metric_Pad1.20x1.40mm_HandSolder; LCSC C17414
R6: 75k; R_0805_2012Metric_Pad1.20x1.40mm_HandSolder; LCSC C17819
R7: 47k; R_0805_2012Metric_Pad1.20x1.40mm_HandSolder; LCSC C17713
R16: 1k; R_0805_2012Metric_Pad1.20x1.40mm_HandSolder; LCSC C17513
TP5: TestPoint; TestPoint_Pad_1.5x1.5mm

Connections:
/Aux/IgnitionPower: J10.1; also elsewhere on the board
/MCU/PyroADC: R16.2; also elsewhere on the board
/MCU/PyroIgnite: R4.2; also elsewhere on the board
GND: Q4.2 (S), R5.2, R7.2; also elsewhere on the board
unnamed: J10.2, Q4.3 (D), R6.2
unnamed: Q4.1 (G), R4.1, R5.1, TP5.1 (1_1)
unnamed: R6.1, R7.1, R16.1

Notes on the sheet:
Low-Side Mosfet Switch for pulling igniton to ground
Continuity detection with adc resistors to protect adc pins

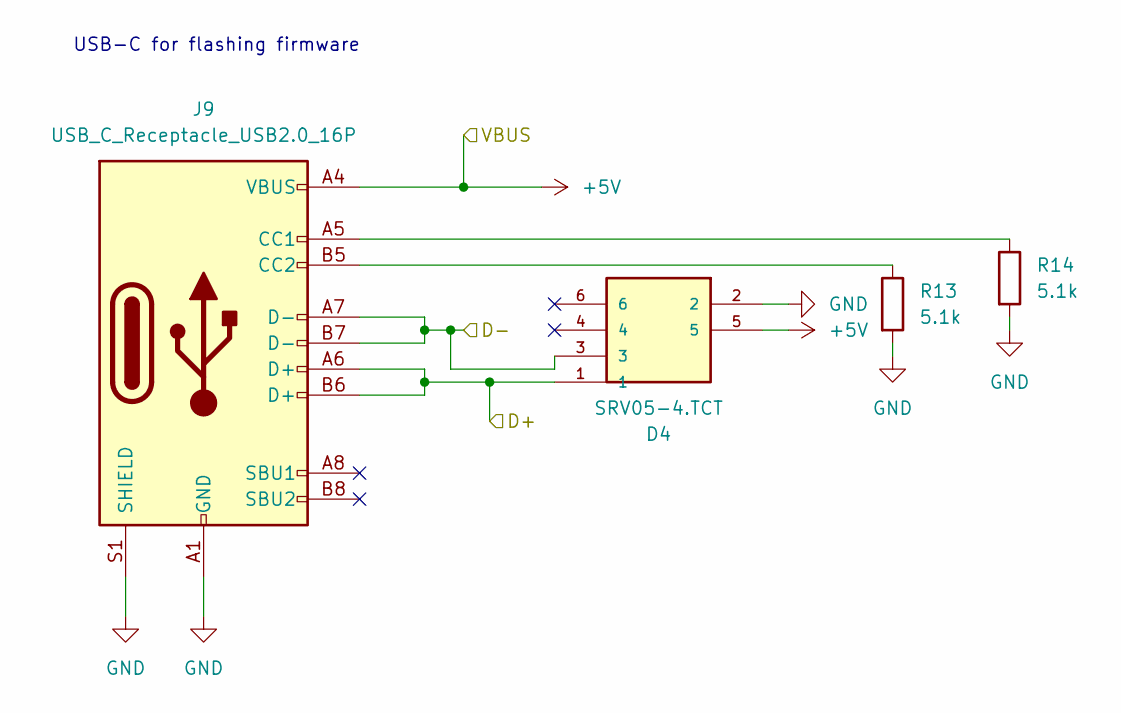
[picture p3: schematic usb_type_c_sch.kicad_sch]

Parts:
D4: SRV05-4.TCT; SOT95P280X145-6N; MANUFACTURER_PART_NUMBER SRV05-4.TCT; LCSC C13612
J9: USB_C_Receptacle_USB2.0_16P; USB_C_Receptacle_HRO_TYPE-C-31-M-12; LCSC C165948
R13, R14: 5.1k; R_0805_2012Metric_Pad1.20x1.40mm_HandSolder; LCSC C27834

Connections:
+5V: D4.5, J9.A4 (VBUS), J9.A9 (VBUS), J9.B4 (VBUS), J9.B9 (VBUS); also elsewhere on the board
/usb_type_c/D+: D4.1, J9.A6 (D+), J9.B6 (D+); also elsewhere on the board
/usb_type_c/D-: D4.3, J9.A7 (D-), J9.B7 (D-); also elsewhere on the board
GND: D4.2, J9.A1 (GND), J9.A12 (GND), J9.B1 (GND), J9.B12 (GND), J9.S1 (SHIELD), R13.2, R14.2; also elsewhere on the board
unnamed: J9.A5 (CC1), R14.1
unnamed: J9.B5 (CC2), R13.1

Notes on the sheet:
USB-C for flashing firmware

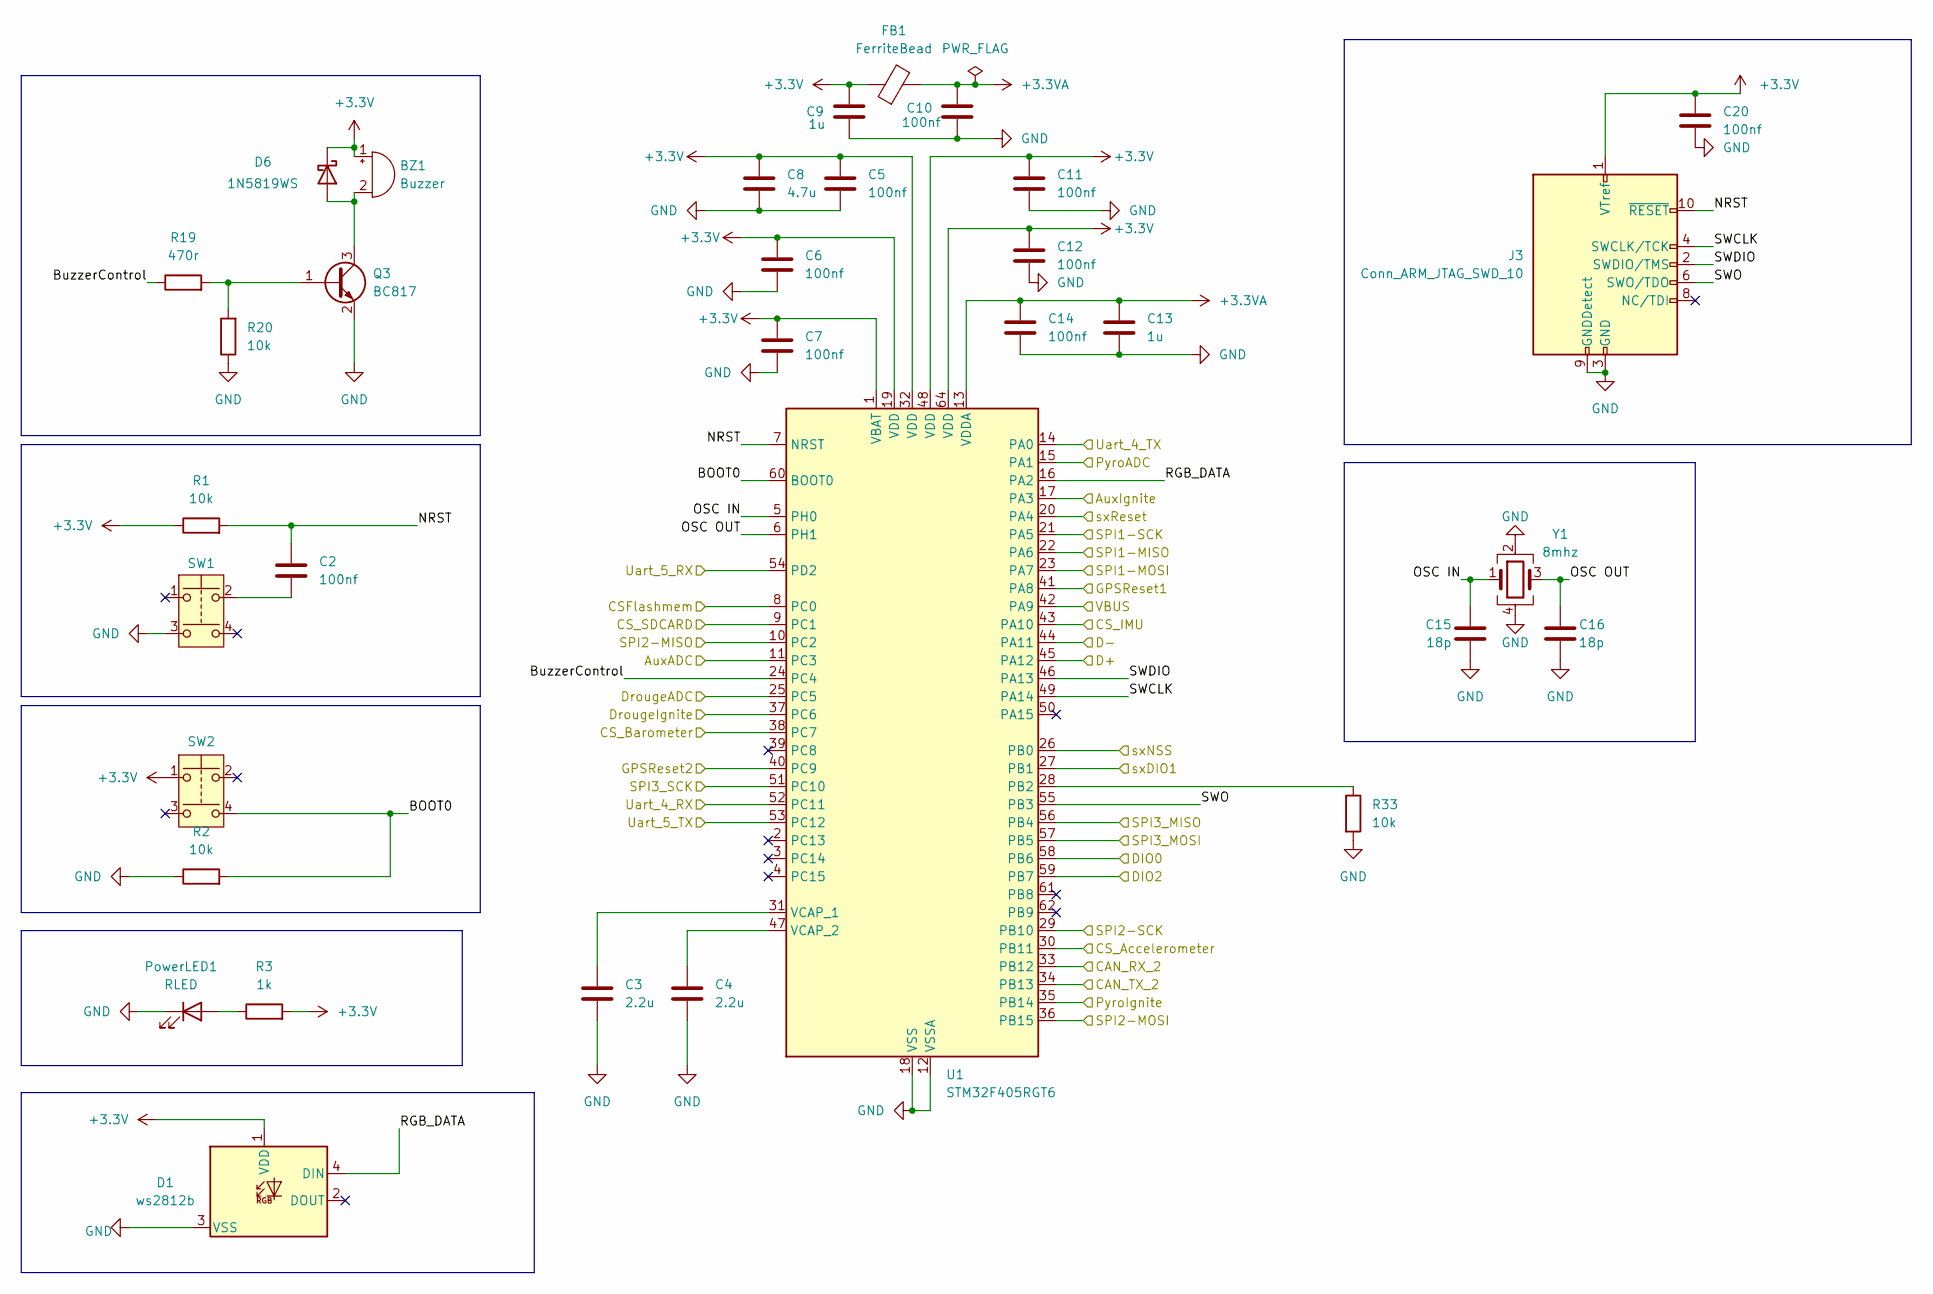
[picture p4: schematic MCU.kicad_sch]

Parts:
BZ1: Buzzer; Buzzer_12x9.5RM7.6; LCSC C96093
C2, C5, C6, C7, C10, C11, C12, C14, C20: 100nf; C_0805_2012Metric_Pad1.18x1.45mm_HandSolder; LCSC C49678
C3, C4: 2.2u; C_0805_2012Metric_Pad1.18x1.45mm_HandSolder; LCSC C377773
C8: 4.7u; C_0805_2012Metric_Pad1.18x1.45mm_HandSolder; LCSC C1779
C9, C13: 1u; C_0805_2012Metric_Pad1.18x1.45mm_HandSolder; LCSC C28323
C15, C16: 18p; C_0805_2012Metric_Pad1.18x1.45mm_HandSolder; LCSC C113825
D1: ws2812b; LED_WS2812B_PLCC4_5.0x5.0mm_P3.2mm; LCSC C2761795
D6: 1N5819WS; D_SOD-323; LCSC C191023
FB1: FerriteBead; R_0805_2012Metric_Pad1.20x1.40mm_HandSolder; LCSC C1015
J3: Conn_ARM_JTAG_SWD_10; PinHeader_2x05_P1.27mm_Vertical
PowerLED1: RLED; LED_0603_1608Metric_Pad1.05x0.95mm_HandSolder; LCSC C965799
Q3: BC817; SOT-23; LCSC C39828
R1, R20: 10k; R_0805_2012Metric_Pad1.20x1.40mm_HandSolder; LCSC C17414
R2: 10k; R_0805_2012Metric_Pad1.20x1.40mm_HandSolder; LCSC C149504
R3: 1k; R_0805_2012Metric_Pad1.20x1.40mm_HandSolder; LCSC C17513
R19: 470r; R_0805_2012Metric_Pad1.20x1.40mm_HandSolder; LCSC C17710
R33: 10k; R_0805_2012Metric
SW1, SW2: SAMZO G4R0015010; LCSC C49393646
U1: STM32F405RGT6; LQFP-64_10x10mm_P0.5mm; LCSC C15742
Y1: 8mhz; Crystal_SMD_3225-4Pin_3.2x2.5mm_HandSoldering; LCSC C19723344

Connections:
+3.3V: BZ1.1 (+), C5.1, C6.1, C7.1, C8.1, C9.2, C11.1, C12.1, C20.1, D1.1 (VDD), D6.1 (K), FB1.1, J3.1 (VTref), R1.1, R3.2, SW2.1, U1.1 (VBAT), U1.19 (VDD), U1.32 (VDD), U1.48 (VDD), U1.64 (VDD); also elsewhere on the board
+3.3VA: C10.2, C13.1, C14.1, FB1.2, U1.13 (VDDA)
+5V: U1.42 (PA9); also elsewhere on the board
/Accelerometer/Accelerometer_MIS0: U1.22 (PA6); also elsewhere on the board
/Accelerometer/Accelerometer_MOSI: U1.23 (PA7); also elsewhere on the board
/Accelerometer/Accelerometer_SPICLK: U1.21 (PA5); also elsewhere on the board
/Accelerometer/ChipslectAccelerometer: U1.30 (PB11); also elsewhere on the board
/Aux/AuxADC: U1.11 (PC3); also elsewhere on the board
/Aux/AuxIgnite: U1.17 (PA3); also elsewhere on the board
/Barometer/Baraometer-ChipSelect: U1.38 (PC7); also elsewhere on the board
/Can_transceiver/CAN_RX_2: U1.33 (PB12); also elsewhere on the board
/Can_transceiver/CAN_TX_2: U1.34 (PB13); also elsewhere on the board
/Drogue/DrougeADC: U1.25 (PC5); also elsewhere on the board
/Drogue/DrougeIgnite: U1.37 (PC6); also elsewhere on the board
/FlashMemory/ChipSelectFLash: U1.8 (PC0); also elsewhere on the board
/FlashMemory/SPICLK: U1.51 (PC10); also elsewhere on the board
/FlashMemory/SPI_MISO: U1.56 (PB4); also elsewhere on the board
/FlashMemory/SPI_MOSI: U1.57 (PB5); also elsewhere on the board
/FlashSd/ChipSelectSDCARD: U1.9 (PC1); also elsewhere on the board
/GPS/GPS1_RX: U1.14 (PA0); also elsewhere on the board
/GPS/GPS1_TX: U1.52 (PC11); also elsewhere on the board
/GPS/GPS2_RX: U1.53 (PC12); also elsewhere on the board
/GPS/GPS2_TX: U1.54 (PD2); also elsewhere on the board
/GPS/RESET1: U1.41 (PA8); also elsewhere on the board
/GPS/RESET2: U1.40 (PC9); also elsewhere on the board
/IMU/ChipSelectIMU: U1.43 (PA10); also elsewhere on the board
/LoRa/sxDIO0: U1.58 (PB6); also elsewhere on the board
/LoRa/sxDIO1: U1.27 (PB1); also elsewhere on the board
/LoRa/sxDIO2: U1.59 (PB7); also elsewhere on the board
/LoRa/sxMIS0: U1.10 (PC2); also elsewhere on the board
/LoRa/sxMOSI: U1.36 (PB15); also elsewhere on the board
/LoRa/sxNSS: U1.26 (PB0); also elsewhere on the board
/LoRa/sxReset: U1.20 (PA4); also elsewhere on the board
/LoRa/sxSCK: U1.29 (PB10); also elsewhere on the board
/MCU/BOOT0: R2.2, SW2.4, U1.60 (BOOT0)
/MCU/BuzzerControl: R19.1, U1.24 (PC4)
/MCU/D+: U1.45 (PA12); also elsewhere on the board
/MCU/D-: U1.44 (PA11); also elsewhere on the board
/MCU/NRST: C2.1, J3.10 (~RESET), R1.2, U1.7 (NRST)
/MCU/OSC IN: C15.1, U1.5 (PH0), Y1.1
/MCU/OSC OUT: C16.1, U1.6 (PH1), Y1.3
/MCU/PyroADC: U1.15 (PA1); also elsewhere on the board
/MCU/PyroIgnite: U1.35 (PB14); also elsewhere on the board
/MCU/RGB_DATA: D1.4 (DIN), U1.16 (PA2)
/MCU/SWCLK: J3.4 (SWCLK/TCK), U1.49 (PA14)
/MCU/SWDIO: J3.2 (SWDIO/TMS), U1.46 (PA13)
/MCU/SWO: J3.6 (SWO/TDO), U1.55 (PB3)
GND: C3.2, C4.2, C5.2, C6.2, C7.2, C8.2, C9.1, C10.1, C11.2, C12.2, C13.2, C14.2, C15.2, C16.2, C20.2, D1.3 (VSS), J3.3 (GND), J3.5 (GND), J3.9 (GNDDetect), PowerLED1.1 (K), Q3.2 (E), R2.1, R20.1, R33.2, SW1.3, U1.12 (VSSA), U1.18 (VSS), U1.63 (VSS), Y1.2, Y1.4; also elsewhere on the board
unnamed: BZ1.2 (-), D6.2 (A), Q3.3 (C)
unnamed: C2.2, SW1.2
unnamed: PowerLED1.2 (A), R3.1
unnamed: Q3.1 (B), R19.2, R20.2
unnamed: R33.1, U1.28 (PB2)
unnamed: C3.1, U1.31 (VCAP_1)
unnamed: C4.1, U1.47 (VCAP_2)

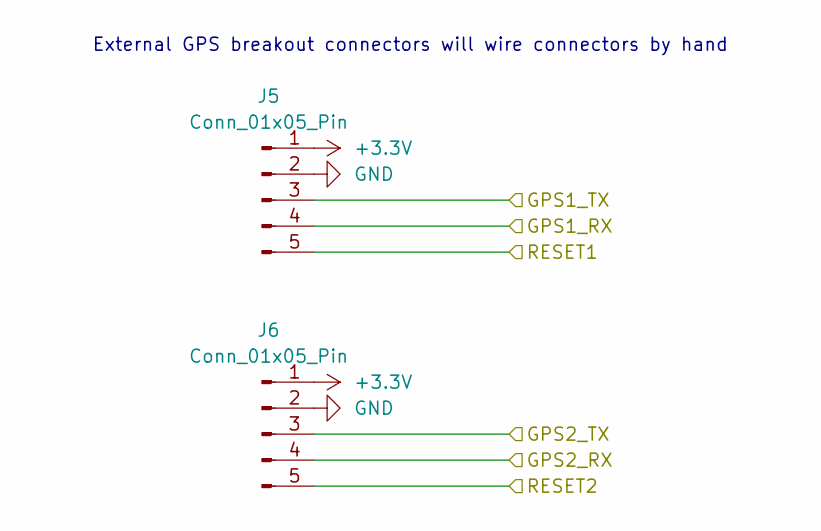
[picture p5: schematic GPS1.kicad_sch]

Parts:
J5, J6: Conn_01x05_Pin; JST_B5B-XH-A; LCSC C157991

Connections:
+3.3V: J5.1, J6.1; also elsewhere on the board
/GPS/GPS1_RX: J5.4; also elsewhere on the board
/GPS/GPS1_TX: J5.3; also elsewhere on the board
/GPS/GPS2_RX: J6.4; also elsewhere on the board
/GPS/GPS2_TX: J6.3; also elsewhere on the board
/GPS/RESET1: J5.5; also elsewhere on the board
/GPS/RESET2: J6.5; also elsewhere on the board
GND: J5.2, J6.2; also elsewhere on the board

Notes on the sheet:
External GPS breakout connectors will wire connectors by hand

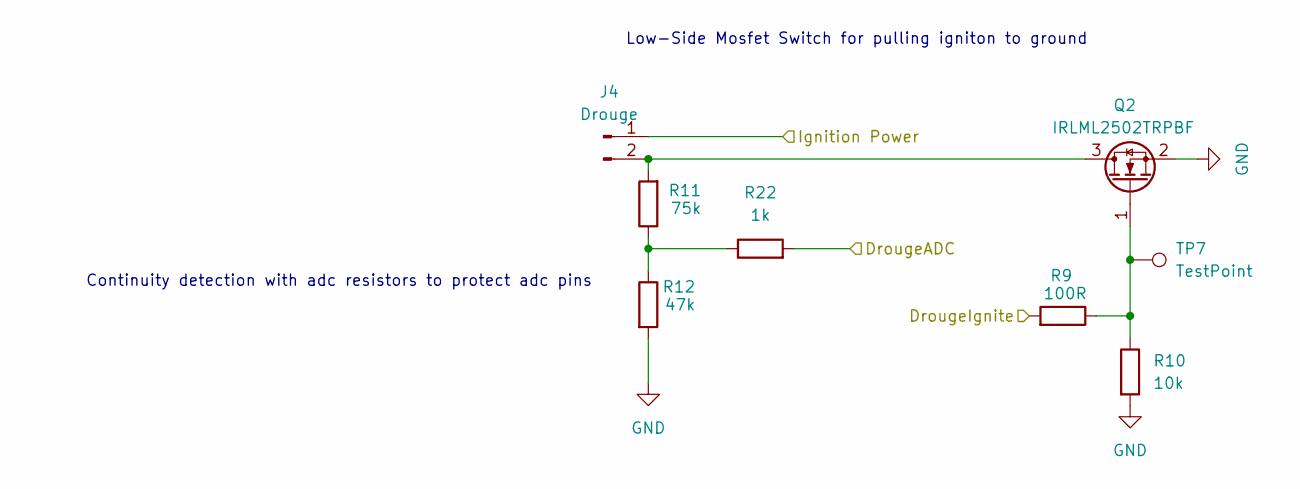
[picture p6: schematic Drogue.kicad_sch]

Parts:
J4: Drouge; MOLEX_26013114; LCSC C17644051
Q2: IRLML2502TRPBF; SOT23; LCSC C2589
R9: 100R; R_0805_2012Metric_Pad1.20x1.40mm_HandSolder; LCSC C17408
R10: 10k; R_0805_2012Metric_Pad1.20x1.40mm_HandSolder; LCSC C17414
R11: 75k; R_0805_2012Metric_Pad1.20x1.40mm_HandSolder; LCSC C17819
R12: 47k; R_0805_2012Metric_Pad1.20x1.40mm_HandSolder; LCSC C17713
R22: 1k; R_0805_2012Metric_Pad1.20x1.40mm_HandSolder; LCSC C17513
TP7: TestPoint; TestPoint_Pad_1.5x1.5mm

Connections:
/Aux/IgnitionPower: J4.1; also elsewhere on the board
/Drogue/DrougeADC: R22.2; also elsewhere on the board
/Drogue/DrougeIgnite: R9.2; also elsewhere on the board
GND: Q2.2 (S), R10.2, R12.2; also elsewhere on the board
unnamed: J4.2, Q2.3 (D), R11.2
unnamed: Q2.1 (G), R9.1, R10.1, TP7.1 (1_1)
unnamed: R11.1, R12.1, R22.1

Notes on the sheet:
Continuity detection with adc resistors to protect adc pins
Low-Side Mosfet Switch for pulling igniton to ground

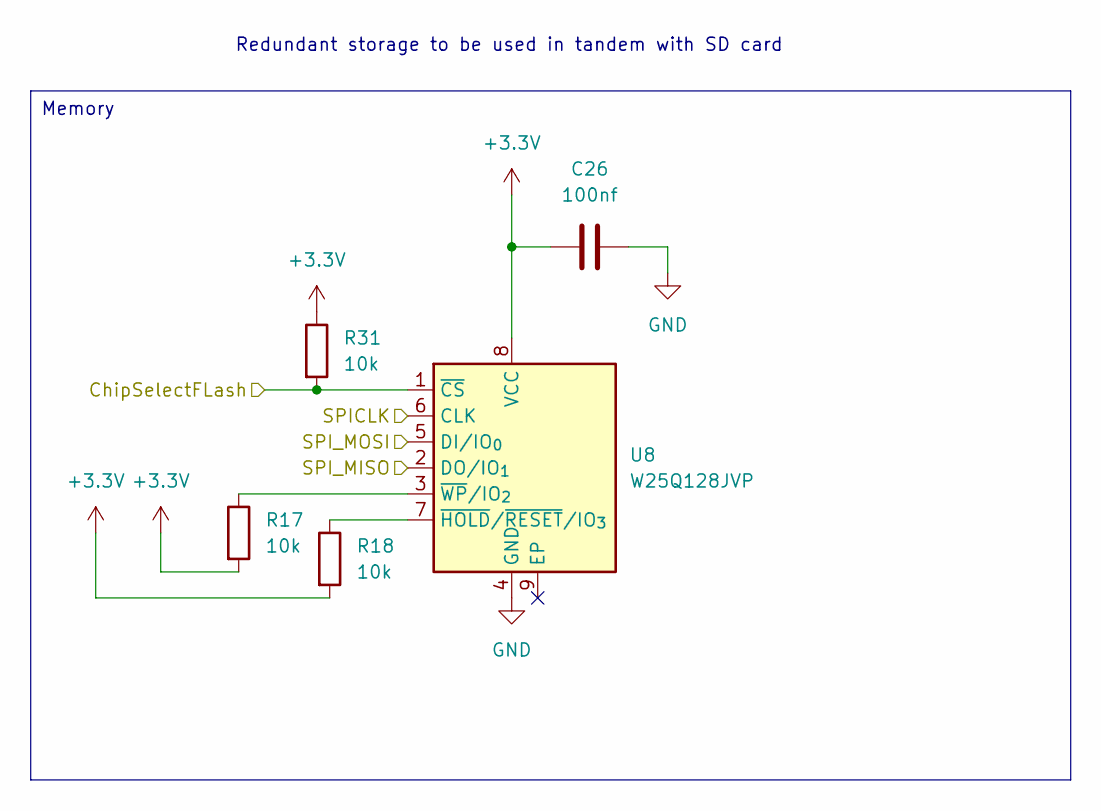
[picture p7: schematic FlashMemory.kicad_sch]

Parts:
C26: 100nf; C_0805_2012Metric_Pad1.18x1.45mm_HandSolder; LCSC C49678
R17, R18, R31: 10k; R_0805_2012Metric_Pad1.20x1.40mm_HandSolder; LCSC C17414
U8: W25Q128JVP; WSON-8-1EP_6x5mm_P1.27mm_EP3.4x4.3mm; LCSC C190862

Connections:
+3.3V: C26.1, R17.2, R18.2, R31.1, U8.8 (VCC); also elsewhere on the board
/FlashMemory/ChipSelectFLash: R31.2, U8.1 (~CS); also elsewhere on the board
/FlashMemory/SPICLK: U8.6 (CLK); also elsewhere on the board
/FlashMemory/SPI_MISO: U8.2 (DO/IO_{1}); also elsewhere on the board
/FlashMemory/SPI_MOSI: U8.5 (DI/IO_{0}); also elsewhere on the board
GND: C26.2, U8.4 (GND); also elsewhere on the board
unnamed: R18.1, U8.7 (~HOLD/~RESET/IO_{3})
unnamed: R17.1, U8.3 (~WP/IO_{2})

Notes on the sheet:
Redundant storage to be used in tandem with SD card
Memory

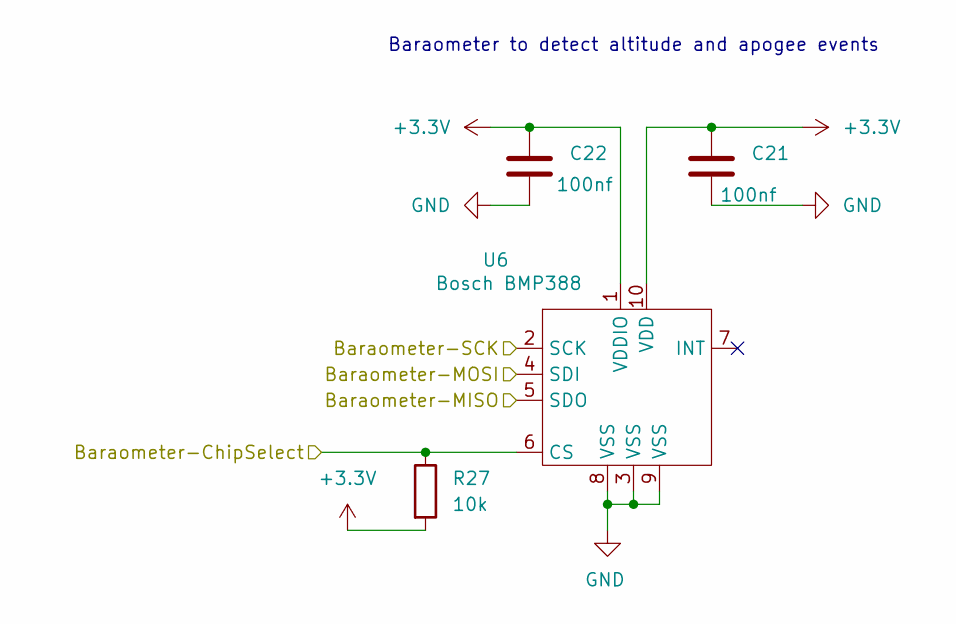
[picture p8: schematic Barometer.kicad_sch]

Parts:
C21, C22: 100nf; C_0805_2012Metric_Pad1.18x1.45mm_HandSolder; LCSC C49678
R27: 10k; R_0805_2012Metric_Pad1.20x1.40mm_HandSolder; LCSC C17414
U6: Bosch BMP388; PQFN50P200X200X80-10N; LCSC C779278

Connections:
+3.3V: C21.1, C22.1, R27.2, U6.1 (VDDIO), U6.10 (VDD); also elsewhere on the board
/Accelerometer/Accelerometer_MIS0: U6.5 (SDO); also elsewhere on the board
/Accelerometer/Accelerometer_MOSI: U6.4 (SDI); also elsewhere on the board
/Accelerometer/Accelerometer_SPICLK: U6.2 (SCK); also elsewhere on the board
/Barometer/Baraometer-ChipSelect: R27.1, U6.6 (CS); also elsewhere on the board
GND: C21.2, C22.2, U6.3 (VSS), U6.8 (VSS), U6.9 (VSS); also elsewhere on the board

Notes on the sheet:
Baraometer to detect altitude and apogee events

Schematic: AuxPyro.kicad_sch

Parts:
J2: Pyro; MOLEX_26013114; LCSC C17644051
Q1: IRLML2502TRPBF; SOT23; LCSC C2589
R21: 1k; R_0805_2012Metric_Pad1.20x1.40mm_HandSolder; LCSC C17513
R23: 100R; R_0805_2012Metric_Pad1.20x1.40mm_HandSolder; LCSC C17408
R24: 10k; R_0805_2012Metric_Pad1.20x1.40mm_HandSolder; LCSC C17414
R25: 75k; R_0805_2012Metric_Pad1.20x1.40mm_HandSolder; LCSC C17819
R26: 47k; R_0805_2012Metric_Pad1.20x1.40mm_HandSolder; LCSC C17713
TP6: TestPoint; TestPoint_Pad_1.5x1.5mm

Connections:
/Aux/AuxADC: R21.2; also elsewhere on the board
/Aux/AuxIgnite: R23.2; also elsewhere on the board
/Aux/IgnitionPower: J2.1; also elsewhere on the board
GND: Q1.2 (S), R24.2, R26.2; also elsewhere on the board
unnamed: J2.2, Q1.3 (D), R25.2
unnamed: Q1.1 (G), R23.1, R24.1, TP6.1 (1_1)
unnamed: R21.1, R25.1, R26.1

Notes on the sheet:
Continuity detection with adc resistors to protect adc pins
Low-Side Mosfet Switch for pulling igniton to ground

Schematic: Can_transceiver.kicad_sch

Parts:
C17: 100nf; C_0805_2012Metric_Pad1.18x1.45mm_HandSolder; LCSC C49678
CAN_IN1: CAN; MOLEX_26013114; LCSC C17644051
CAN_OUT1: CAN; MOLEX_26013114; LCSC C17644051
JP1: SolderJumper_2_Open; SolderJumper-2_P1.3mm_Open_TrianglePad1.0x1.5mm; not fitted
R8: 120R; R_0805_2012Metric_Pad1.20x1.40mm_HandSolder; LCSC C17437
U2: SN65HVD230; SOIC-8_3.9x4.9mm_P1.27mm; LCSC C12084

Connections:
+3.3V: C17.1, U2.3 (VCC); also elsewhere on the board
/Can_transceiver/CANH: CAN_IN1.1, CAN_OUT1.1, R8.1, U2.7 (CANH)
/Can_transceiver/CANL: CAN_IN1.2, CAN_OUT1.2, JP1.2 (B), U2.6 (CANL)
/Can_transceiver/CAN_RX_2: U2.4 (R); also elsewhere on the board
/Can_transceiver/CAN_TX_2: U2.1 (D); also elsewhere on the board
GND: C17.2, U2.2 (GND), U2.8 (Rs); also elsewhere on the board
unnamed: JP1.1 (A), R8.2

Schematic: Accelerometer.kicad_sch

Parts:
C27: 100nf; C_0805_2012Metric_Pad1.18x1.45mm_HandSolder; LCSC C49678
C28: 1u; C_0805_2012Metric_Pad1.18x1.45mm_HandSolder; LCSC C28323
R32: 10k; R_0805_2012Metric_Pad1.20x1.40mm_HandSolder; LCSC C17414
U9: H3LIS331DL; PQFN50P300X300X100-16N; LCSC C2655074

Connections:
+3.3V: C27.2, C28.2, R32.1, U9.1 (Vdd_IO), U9.14 (VDD), U9.15 (VDD); also elsewhere on the board
/Accelerometer/Accelerometer_MIS0: U9.7 (SDO/SA0); also elsewhere on the board
/Accelerometer/Accelerometer_MOSI: U9.6 (SDA/SDI/SDO); also elsewhere on the board
/Accelerometer/Accelerometer_SPICLK: U9.4 (SCL/SPC); also elsewhere on the board
/Accelerometer/ChipslectAccelerometer: R32.2, U9.8 (CS); also elsewhere on the board
GND: C27.1, C28.1, U9.5 (GND), U9.12 (GND); also elsewhere on the board

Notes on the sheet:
High g imu for liftoff data

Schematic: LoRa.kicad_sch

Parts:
C1: 100nf; C_0805_2012Metric_Pad1.18x1.45mm_HandSolder; LCSC C49678
J7: Conn_Coaxial_Small; SMA_Amphenol_132291_Vertical; LCSC C3172376
U5: RFM95W-915S2; XCVR_RFM95W-915S2; LCSC C2844473

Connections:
+3.3V: C1.1, U5.13 (3.3V); also elsewhere on the board
/LoRa/sxDIO0: U5.14 (DIO0); also elsewhere on the board
/LoRa/sxDIO1: U5.15 (DIO1); also elsewhere on the board
/LoRa/sxDIO2: U5.16 (DIO2); also elsewhere on the board
/LoRa/sxMIS0: U5.2 (MISO); also elsewhere on the board
/LoRa/sxMOSI: U5.3 (MOSI); also elsewhere on the board
/LoRa/sxNSS: U5.5 (NSS); also elsewhere on the board
/LoRa/sxReset: U5.6 (RESET); also elsewhere on the board
/LoRa/sxSCK: U5.4 (SCK); also elsewhere on the board
GND: C1.2, J7.2 (Ext), U5.1 (GND), U5.8 (GND), U5.10 (GND); also elsewhere on the board
unnamed: J7.1 (In), U5.9 (ANT)

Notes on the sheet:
Lora module to coaxial connector

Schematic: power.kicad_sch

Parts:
C18: 100nf; C_0805_2012Metric_Pad1.18x1.45mm_HandSolder; LCSC C49678
C19: 10u; C_0805_2012Metric_Pad1.18x1.45mm_HandSolder; LCSC C15850
D2, D3: D_Schottky; D_2114_3652Metric; LCSC C113936
Q6: Q_PMOS_GSD; SOIC127P599X175-8N; LCSC C16072
R30: 47k; R_0805_2012Metric_Pad1.20x1.40mm_HandSolder; LCSC C17713
TP1, TP2, TP3: TestPoint; TestPoint_Pad_1.5x1.5mm
TP4: TestPoint; TestPoint_Pad_2.5x2.5mm
U3: PowerIn; MOLEX_26013114; LCSC C17644051
U4: LDL1117-3.3; SOT230P700X180-4N; LCSC C435835

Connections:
+3.3V: C19.1, TP3.1 (1_1), U4.2 (Vout), U4.4 (Vout); also elsewhere on the board
+5V: D3.2 (A); also elsewhere on the board
+BATT: Q6.1 (S), Q6.2 (Source), Q6.3 (Source), TP1.1 (1_1), U3.1
/Aux/IgnitionPower: D2.2 (A), Q6.5 (D), Q6.6 (Drain), Q6.7 (Drain), TP2.1 (1_1); also elsewhere on the board
GND: C18.2, C19.2, R30.2, TP4.1 (1_1), U3.2, U4.1 (GND); also elsewhere on the board
unnamed: C18.1, D2.1 (K), D3.1 (K), U4.3 (Vin)
unnamed: Q6.4 (G), R30.1

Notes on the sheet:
Flowback protection for usb and battery
The main protection point for the mosfet is the adc continuty checking pins
P-mosfet for reverse polarity protection (be advised extra pins are there just to sync with the footprint but treated as a normal p-mosfet)
Power in connector

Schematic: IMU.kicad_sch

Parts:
C24, C25: 100nf; C_0805_2012Metric_Pad1.18x1.45mm_HandSolder; LCSC C49678
R36: 10k; R_0805_2012Metric_Pad1.20x1.40mm_HandSolder; LCSC C17414
U7: LSM6DS3TR-C; LGA-14-2.5X3MM; LCSC C2655100

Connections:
+3.3V: C24.1, C25.1, R36.1, U7.2 (SDx), U7.3 (SCx), U7.5 (VDDIO), U7.8 (VDD); also elsewhere on the board
/Accelerometer/Accelerometer_MIS0: U7.1 (SDO/SA0); also elsewhere on the board
/Accelerometer/Accelerometer_MOSI: U7.14 (SDA); also elsewhere on the board
/Accelerometer/Accelerometer_SPICLK: U7.13 (SCL); also elsewhere on the board
/IMU/ChipSelectIMU: R36.2, U7.12 (CS); also elsewhere on the board
GND: C24.2, C25.2, U7.6 (GND), U7.7 (GND); also elsewhere on the board

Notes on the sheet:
Imu for control systems and data logging

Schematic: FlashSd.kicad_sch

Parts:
J8: Micro_SD_Card; microSD_HC_Molex_47219-2001; LCSC C164170
R15: 10k; R_0805_2012Metric_Pad1.20x1.40mm_HandSolder; LCSC C17414

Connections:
+3.3V: J8.4 (VDD), R15.1; also elsewhere on the board
/FlashMemory/SPICLK: J8.5 (CLK); also elsewhere on the board
/FlashMemory/SPI_MISO: J8.3 (CMD); also elsewhere on the board
/FlashMemory/SPI_MOSI: J8.7 (DAT0); also elsewhere on the board
/FlashSd/ChipSelectSDCARD: J8.2 (DAT3/CD), R15.2; also elsewhere on the board
GND: J8.6 (VSS), J8.9 (SHIELD); also elsewhere on the board

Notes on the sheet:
SD Card for flight telemetry logging and possible lookup tables for control systems

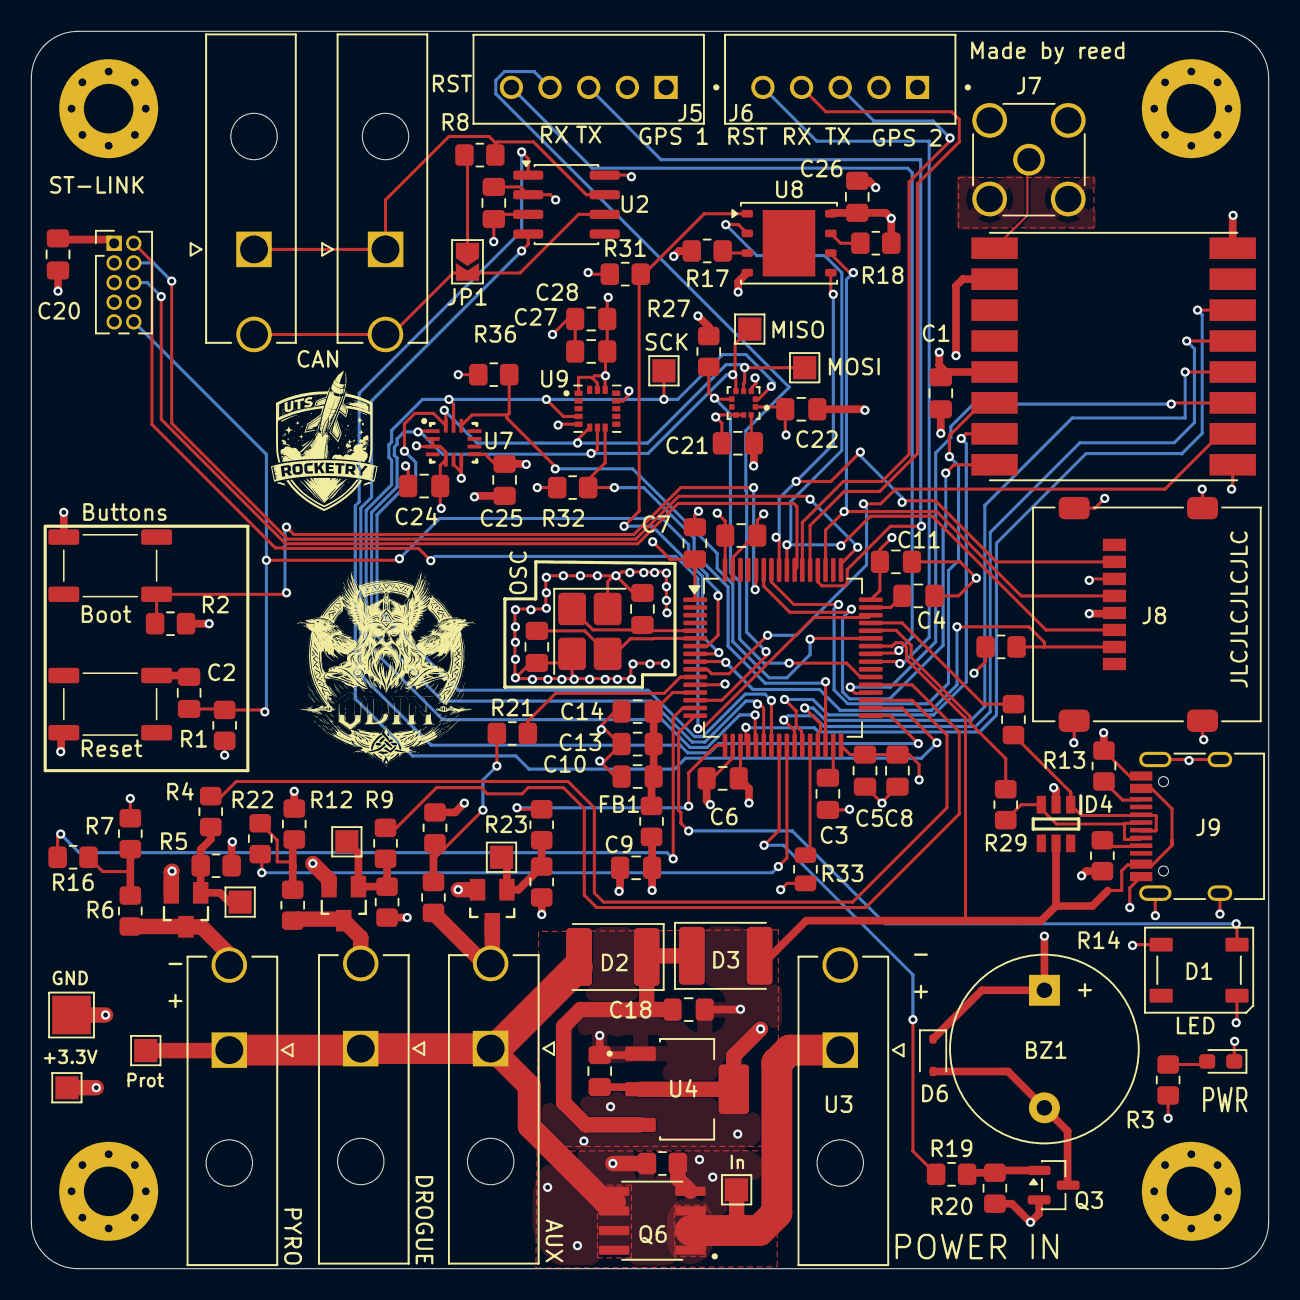
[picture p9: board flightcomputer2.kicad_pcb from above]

Board: 4 copper layers, 80.0 x 80.0 mm, 108 parts (0 on the bottom side), 78 nets.

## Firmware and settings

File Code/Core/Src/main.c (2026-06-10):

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
/* Includes ------------------------------------------------------------------*/
#include "main.h"
#include "fatfs.h"

/* USER CODE BEGIN Includes */

#include "BMP388.h"
#include <stdint.h>
#include <stdio.h>
#include "lsm6dsox_reg.h"
#include "h3lis331dl_reg.h"
#include "stm32f4xx_hal.h"
#include "stm32f4xx_hal_def.h"
#include "flight_sensors.h"
#include "indicators.h"
#include "telemetry.h"
#include "Lora_App.h"
#include "pyro.h"
#include "flight_state.h"
#include "kalman.h"


/* USER CODE END Includes */

ADC_HandleTypeDef hadc1;
ADC_HandleTypeDef hadc2;

CAN_HandleTypeDef hcan2;

IWDG_HandleTypeDef hiwdg;

SPI_HandleTypeDef hspi1;
SPI_HandleTypeDef hspi2;
SPI_HandleTypeDef hspi3;

UART_HandleTypeDef huart4;
UART_HandleTypeDef huart5;

PCD_HandleTypeDef hpcd_USB_OTG_FS;

/* sensor data is declared in main and it is used for FSM decisions
   it also is passed to telemetry.c to pass telemetry to ground station */
FlightSensorData sensorData;

uint8_t imu_sensor_read = 0;
uint8_t baro_sensor_read = 0;

void SystemClock_Config(void);
static void MX_GPIO_Init(void);
static void MX_ADC1_Init(void);
static void MX_ADC2_Init(void);
static void MX_CAN2_Init(void);
static void MX_SPI1_Init(void);
static void MX_SPI2_Init(void);
static void MX_USB_OTG_FS_PCD_Init(void);
static void MX_UART4_Init(void);
static void MX_UART5_Init(void);
static void MX_SPI3_Init(void);
static void MX_IWDG_Init(void);
/* USER CODE BEGIN 0 */

/* This is a debug printf that exposes uart through the gps header pins*/
#ifdef DEBUG
int _write(int file, char *ptr, int len) {
    HAL_UART_Transmit(&huart4, (uint8_t*)ptr, len, HAL_MAX_DELAY);
    return len;
}

#endif

/* USER CODE END 0 */

/**
  * @brief  The application entry point.
  * @retval int
  */
int main(void)
{

  /* USER CODE BEGIN 1 */
  
  /* result is used to check status of any HAL functions and return error codes */
  HAL_StatusTypeDef result;

  /* USER CODE END 1 */

  /* MCU Configuration--------------------------------------------------------*/

  /* Reset of all peripherals, Initializes the Flash interface and the Systick. */
  HAL_Init();

  /* Configure the system clock */
  SystemClock_Config();

  /* Initialize all configured peripherals */
  MX_GPIO_Init();
  MX_ADC1_Init();
  MX_ADC2_Init();
  MX_CAN2_Init();
  MX_SPI1_Init();
  MX_SPI2_Init();
  MX_USB_OTG_FS_PCD_Init();
  MX_UART4_Init();
  MX_UART5_Init();
  MX_SPI3_Init();
  //MX_FATFS_Init();
  /* USER CODE BEGIN 2 */


  /*THIS IS FOR SD card but it is wired wrong*/
  /* FRESULT fr = f_mount(&USERFatFS, USERPath, 1);
  printf("f_mount: %d\r\n", (int)fr); */
  
  
 result = flight_sensors_init();
 
 #ifdef DEBUG
  if (result != HAL_OK) {
    printf("Flight sensors Init Failed\r\n");
  } else {
    printf("Flight sensors  Init Successfull\r\n");
  }
  
 #endif
 #ifdef BARO_NOISE_TEST
  // after flight_sensors_init(), loop and just print raw altitude
  while (1) {
      flight_sensors_update_baro(&sensorData);
      printf("%.4f\r\n", sensorData.altitude);   // one value per line
      HAL_Delay(40);   // match your baro rate
  }
 #endif
 
 result = lora_App_Init();
 
 #ifdef DEBUG
    if (result != HAL_OK) {

      printf("Lora Init Failed\r\n");

    } else {
      printf("Lora Init Successfull\r\n");
    }
  #endif

  result = flash_memory_init();
  #ifdef DEBUG
    if (result != HAL_OK) {
      printf("flash memory failed\r\n");
    } else { 
      printf("Flash memory OK");
    }
  #endif

  result = flash_sanity_check();
  
  #ifdef DEBUG
    if (result != HAL_OK) {
      printf("flash memory failed\r\n");
    } else { 
      printf("Flash memory OK\r\n");
    }
  #endif


  kalman_init();
  pyro_init();
  FSM_init();
  buzzer_init();

  MX_IWDG_Init();

  #ifdef DEBUG
  uint32_t last = HAL_GetTick();
  #endif

  uint32_t last_imu   = 0;
  uint32_t last_baro  = 0;
  uint32_t last_lora  = 0;
  uint32_t last_flash = 0;
  uint32_t last_cont  = 0;
  uint32_t last_RX    = 0;
  #ifdef DEBUG
    if (__HAL_RCC_GET_FLAG(RCC_FLAG_IWDGRST)) printf("!!! IWDG RESET !!!\r\n");
    __HAL_RCC_CLEAR_RESET_FLAGS();
  #endif
  
  /* USER CODE END 2 */

  /* Infinite loop */
  /* USER CODE BEGIN WHILE */
  while (1)
  { 
    /* Watch dog woof woof*/
    HAL_IWDG_Refresh(&hiwdg);
    /*This is to get timing loop*/
    uint32_t now = HAL_GetTick();
    
    /*Non blocking pyro*/
    pyro_service();
    indicators_service();
    
    if (now - last_imu >= 10) {
      float dt = (now - last_imu) / 1000.0f;
      last_imu = now;
      HAL_StatusTypeDef imu_result = flight_sensors_update_IMU_accel(&sensorData);
      
      #ifdef DEBUG
          if (imu_result != HAL_OK) printf("sensor update failed\r\n");
      #endif
      
      (void)imu_result;
      kalman_predict(sensorData.z_mg_IMU, dt);
      sensorData.kalman_altitude = kalman_get_altitude();
      sensorData.kalman_velocity = kalman_get_velocity();
      imu_sensor_read = 1;
    }

    if (now - last_baro >= 40) {
      last_baro = now;
      HAL_StatusTypeDef baro_result = flight_sensors_update_baro(&sensorData);
      #ifdef DEBUG
          if (baro_result != HAL_OK) printf("Baro sensor update failed\r\n");
      #endif
      (void) baro_result;
      kalman_update(sensorData.altitude);
      sensorData.kalman_altitude = kalman_get_altitude();
      sensorData.kalman_velocity = kalman_get_velocity();
      baro_sensor_read = 1;
      #ifdef DEBUG
        if(FSM_get_state() >= STATE_BOOST) {
          printf("st=%d alt=%.1f vel=%.1f acc=%.0f\r\n",
              FSM_get_state(),
              sensorData.kalman_altitude,
              sensorData.kalman_velocity,
              sensorData.z_mg_IMU);
        }
      #endif
    }

    if(imu_sensor_read || baro_sensor_read) {
      FSM_update(&sensorData, imu_sensor_read, baro_sensor_read);
      imu_sensor_read = 0; 
      baro_sensor_read = 0;
    }

    sensorData.flight_state = FSM_get_state();
  
    if (now - last_cont >= 2000 && FSM_get_state() <= STATE_PAD) {
      last_cont = now;
      lora_tx_continuity();

    }
    if (FSM_get_state() <= STATE_PAD && now - last_RX >= 400) { last_RX = now; lora_rx_command(); }


    if(now - last_lora >= 300 && FSM_get_state() >= STATE_PAD) {
      last_lora = now;
      lora_tx_telemetry(&sensorData);
    }


    if (now - last_flash >= 40 && FSM_get_state() >= STATE_PAD) {
        last_flash = now;
        flash_log_telemetry(&sensorData);
    }

    /*#ifdef DEBUG
      serial_print(&sensorData);
      uint32_t dt = now - last;
      last = now;
      printf("Sensor loop dt: %lums\r\n", dt);
    #endif
    */
     
    /* USER CODE END WHILE */

    /* USER CODE BEGIN 3 */
  }
  /* USER CODE END 3 */
}

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


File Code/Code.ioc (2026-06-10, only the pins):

Mcu.UserName=STM32F405RGTx
PA0-WKUP.Signal=UART4_TX
PA1.Signal=ADCx_IN1
PA10.GPIO_Label=CS_IMU
PA10.Signal=GPIO_Output
PA11.Signal=USB_OTG_FS_DM
PA12.Signal=USB_OTG_FS_DP
PA13.Signal=SYS_JTMS-SWDIO
PA14.Signal=SYS_JTCK-SWCLK
PA2.GPIO_Label=RGBLEDControl
PA2.Signal=S_TIM2_CH3
PA3.GPIO_Label=AuxIgnite
PA3.Signal=GPIO_Output
PA5.Signal=SPI1_SCK
PA6.Signal=SPI1_MISO
PA7.Signal=SPI1_MOSI
PA8.GPIO_Label=GPS1ResetPin
PA8.Signal=GPIO_Output
PA9.Signal=USB_OTG_FS_VBUS
PB0.GPIO_Label=LoRaNssPin
PB0.Signal=GPIO_Output
PB1.GPIO_Label=LoRaDIO1
PB1.Signal=GPIO_Input
PB10.Signal=SPI2_SCK
PB11.GPIO_Label=CSAccelerometer
PB11.Signal=GPIO_Output
PB12.Signal=CAN2_RX
PB13.Signal=CAN2_TX
PB14.GPIO_Label=PyroIgnite
PB14.Signal=GPIO_Output
PB15.Signal=SPI2_MOSI
PB2.GPIO_Label=LoRaResetPin
PB2.Signal=GPIO_Output
PB3.Signal=SYS_JTDO-SWO
PB4.Signal=SPI3_MISO
PB5.Signal=SPI3_MOSI
PB6.GPIO_Label=LoRaDIO0
PB6.Signal=GPXTI6
PB7.GPIO_Label=LoRaDIO2
PB7.Signal=GPIO_Input
PC0.GPIO_Label=CSFlashmMemory
PC0.Signal=GPIO_Output
PC1.GPIO_Label=CS_SD_Card
PC1.Signal=GPIO_Output
PC10.Signal=SPI3_SCK
PC11.Signal=UART4_RX
PC12.Signal=UART5_TX
PC2.Signal=SPI2_MISO
PC3.Signal=ADCx_IN13
PC4.GPIO_Label=BuzzerControl
PC4.Signal=GPIO_Output
PC5.Signal=ADCx_IN15
PC6.GPIO_Label=DrogueIgnite
PC6.Signal=GPIO_Output
PC7.GPIO_Label=CSBarometer
PC7.Signal=GPIO_Output
PC9.GPIO_Label=GPS2ResetPin
PC9.Signal=GPIO_Output
PD2.Signal=UART5_RX
PH0-OSC_IN.Signal=RCC_OSC_IN
PH1-OSC_OUT.Signal=RCC_OSC_OUT

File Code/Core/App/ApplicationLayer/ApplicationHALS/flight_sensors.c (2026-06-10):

#include "flight_sensors.h"
#include <stdio.h>
#include "BMP388.h"
#include "lsm6dsox_reg.h"
#include "h3lis331dl_reg.h"
#include "main.h"
#include "stm32f4xx_hal_def.h"

extern SPI_HandleTypeDef hspi1;


static BMP388Handle_TypeDef bmp;
static lsm6dso_HandleTypedef imu;
static h3lis331dl_HandleTypeDef accel;

/*BAROMETER VARIABLES*/
static float ground_pressure;

/*ACCEL VARIABLES*/
static int16_t accel_val[3] = {0};
static float accel_offset[3] = {0};

/*IMU VARIABLES*/
static int16_t xl_Val[3] = {0};
static int16_t gy_Val[3] = {0};
static float xl_Offset[3] = {0};
static float gy_Offset[3] = {0};

static void BMP388_handleinit (BMP388Handle_TypeDef *bmp);
static void lsm6dso_handleinit(lsm6dso_HandleTypedef *imu);
static void h3lis331dl_handleinit(h3lis331dl_HandleTypeDef *accel);


/* This function takes initializes the pins for the BMP388 Barometer
   Parameters: BMP388Handle_TypeDef
   returns: void 
   Maybe change later to return a HAL_StatusTypedef for debuging*/
static void BMP388_handleinit (BMP388Handle_TypeDef *bmp) {
  
  /*Set pins and spi*/
  bmp->hspi = &hspi1; 
  bmp->cs_port = CSBarometer_GPIO_Port;
  bmp->cs_pin = CSBarometer_Pin;

  /*This is just for debuging 
    however future implemetation will send status
    over LoRa*/

  if (BMP388_Init(bmp) != HAL_OK) {
    #ifdef DEBUG
      printf("BMP388 init FAILED\r\n");
    #endif
  } else {
    #ifdef DEBUG
      printf("BMP388 OK\r\n");
    #endif
  }

}

static void lsm6dso_handleinit(lsm6dso_HandleTypedef *imu) {
  /* sets the sensor bus and pins */
  imu->hspi = &hspi1;
  imu->cs_port = CS_IMU_GPIO_Port;
  imu->cs_pin = CS_IMU_Pin;

  /* debug statements */
  if (lsm6dso_init(imu) != HAL_OK) {
    #ifdef DEBUG
      printf("IMU init FAILED\r\n");
    #endif
  } else {
    #ifdef DEBUG
      printf("IMU OK\r\n");
    #endif
  }

}

static void h3lis331dl_handleinit(h3lis331dl_HandleTypeDef *accel) {

  /*Sets the struct values from main.h same accoss all senssor and perifierials 
    so we can use the code just need to change the values if ported */
  accel->hspi = &hspi1;
  accel->cs_port = CSAccelerometer_GPIO_Port;
  accel->cs_pin = CSAccelerometer_Pin;

  /* Debug statements */
  if (h3lis331dl_init(accel) != HAL_OK) {
      #ifdef DEBUG
        printf("ACCEL init FAILED\r\n");
      #endif
  } else {
      #ifdef DEBUG
        printf("ACCEL OK\r\n");
      #endif
  }

}

/* This Function is called in main
   Parameters: void
   returns: HAL_StatusTypedef (HAL_OK or HAL_ERROR)
   This function initializes all the sensors on ODIN
   and does calls their calibration functions */

HAL_StatusTypeDef flight_sensors_init(void) {
  

  HAL_StatusTypeDef result;
  
  /*SENSOR INITS*/
  /* BAROMETER INIT */

  BMP388_handleinit(&bmp);
  HAL_Delay(50);


  /* This function is a calibration to find the ground pressure so we dont set altitude to sea level it is to the actuall
     elevation we are at returns a HAL_StatusTypeDef */

  result = BMP388_FindGroundPressure(&bmp, &ground_pressure);
  
  /* Debug statements*/
  if (result != HAL_OK) {  
    #ifdef DEBUG
      printf("Ground pressure error\r\n");
    #endif
    #ifndef HIL_SIM
      return HAL_ERROR;
    #endif
  } 
  
  /*ACCEL INIT*/
  h3lis331dl_handleinit(&accel);
  HAL_Delay(50);
  /* This does the same as barometer however this is due to sensor error and we will average and compensate again to 
     calibrate the sensor */
  result = h3lis331dl_Calibration(accel_offset);
  
  /* debug statements */
  /* Beep OK! */
  if (result != HAL_OK) {
    #ifdef DEBUG
      printf("Accelerometer Calibration Error\r\n");
    #endif
    #ifndef HIL_SIM
      return HAL_ERROR;
    #endif
  } 


  /*IMU INIT*/
  lsm6dso_handleinit(&imu);
  HAL_Delay(50);

  /* creates an offset to be used against sensor values to account for sensor error */
  result = lsm6dso_Calib(xl_Offset, gy_Offset);

  /* debug */
  if (result != HAL_OK) {
    #ifdef DEBUG
      printf("IMU Calibration Error\r\n");
    #endif
    
    #ifndef HIL_SIM
      return HAL_ERROR;
    #endif

  }

  
  /*return HAL_Status Typedef */
  #ifdef HIL_SIM
    return HAL_OK;   /* under sim, ignore sensor init failures */
  #else
    return result;
  #endif
  
}


#ifndef HIL_SIM

HAL_StatusTypeDef flight_sensors_update_baro(FlightSensorData *sensordata) {

  HAL_StatusTypeDef result;
  if (sensordata == NULL) return HAL_ERROR;
  
  result = BMP388_ExternalReadFunction(&bmp, &sensordata->pressure, &sensordata->temperature, &sensordata->altitude, &ground_pressure);
  if (result != HAL_OK) {
    #ifdef DEBUG
      printf("BMP388 Error\r\n");
    #endif
    return result;

  }

  return HAL_OK;

}

HAL_StatusTypeDef flight_sensors_update_IMU_accel(FlightSensorData *sensordata) {
  
  HAL_StatusTypeDef result;
  if (sensordata == NULL) return HAL_ERROR;
  result = h3lis331dl_externalRead(accel_val);
  if (result != HAL_OK) {

    #ifdef DEBUG
      printf("h3lis331dl Error\r\n");
    #endif
    return result;

  } 

  sensordata->x_mg = h3lis331dl_from_fs200_to_mg(accel_val[0]) - accel_offset[0];
  sensordata->y_mg = h3lis331dl_from_fs200_to_mg(accel_val[1]) - accel_offset[1];
  sensordata->z_mg = h3lis331dl_from_fs200_to_mg(accel_val[2]) - accel_offset[2];

  result = lsm6dso_ExternalReader(xl_Val, gy_Val);
  if (result != HAL_OK) {

    #ifdef DEBUG
      printf("lsm6dso Error\r\n");
    #endif
    return result;

  } 

  sensordata->x_mg_IMU = lsm6dsox_from_fs16_to_mg(xl_Val[0]) - xl_Offset[0];
  sensordata->y_mg_IMU = lsm6dsox_from_fs16_to_mg(xl_Val[1]) - xl_Offset[1];
  sensordata->z_mg_IMU = lsm6dsox_from_fs16_to_mg(xl_Val[2]) - xl_Offset[2];

  sensordata->x_gy = lsm6dsox_from_fs2000_to_mdps(gy_Val[0]) - gy_Offset[0];
  sensordata->y_gy = lsm6dsox_from_fs2000_to_mdps(gy_Val[1]) - gy_Offset[1];
  sensordata->z_gy = lsm6dsox_from_fs2000_to_mdps(gy_Val[2]) - gy_Offset[2];
  
  return HAL_OK;

}

#else
#include "sim_profile.h"
#include "flight_state.h"
static uint32_t sim_idx = 0;

HAL_StatusTypeDef flight_sensors_update_IMU_accel(FlightSensorData *d) {
    // hold on the pad sample until armed (FSM reaches PAD), then play the flight
    if (FSM_get_state() >= STATE_PAD && sim_idx < SIM_LEN - 1) {
        sim_idx++;
    }
    d->z_mg_IMU = sim_accel_mg[sim_idx];
    return HAL_OK;
}

HAL_StatusTypeDef flight_sensors_update_baro(FlightSensorData *d) {
    d->altitude = sim_alt[sim_idx];
    return HAL_OK;
}
#endif

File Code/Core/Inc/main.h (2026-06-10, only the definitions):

#define CSFlashmMemory_Pin GPIO_PIN_0
#define CSFlashmMemory_GPIO_Port GPIOC
#define CS_SD_Card_Pin GPIO_PIN_1
#define CS_SD_Card_GPIO_Port GPIOC
#define RGBLEDControl_Pin GPIO_PIN_2
#define RGBLEDControl_GPIO_Port GPIOA
#define AuxIgnite_Pin GPIO_PIN_3
#define AuxIgnite_GPIO_Port GPIOA
#define BuzzerControl_Pin GPIO_PIN_4
#define BuzzerControl_GPIO_Port GPIOC
#define LoRaNssPin_Pin GPIO_PIN_0
#define LoRaNssPin_GPIO_Port GPIOB
#define LoRaDIO1_Pin GPIO_PIN_1
#define LoRaDIO1_GPIO_Port GPIOB
#define LoRaResetPin_Pin GPIO_PIN_2
#define LoRaResetPin_GPIO_Port GPIOB
#define CSAccelerometer_Pin GPIO_PIN_11
#define CSAccelerometer_GPIO_Port GPIOB
#define PyroIgnite_Pin GPIO_PIN_14
#define PyroIgnite_GPIO_Port GPIOB
#define DrogueIgnite_Pin GPIO_PIN_6
#define DrogueIgnite_GPIO_Port GPIOC
#define CSBarometer_Pin GPIO_PIN_7
#define CSBarometer_GPIO_Port GPIOC
#define GPS2ResetPin_Pin GPIO_PIN_9
#define GPS2ResetPin_GPIO_Port GPIOC
#define GPS1ResetPin_Pin GPIO_PIN_8
#define GPS1ResetPin_GPIO_Port GPIOA
#define CS_IMU_Pin GPIO_PIN_10
#define CS_IMU_GPIO_Port GPIOA
#define LoRaDIO0_Pin GPIO_PIN_6
#define LoRaDIO0_GPIO_Port GPIOB
#define LoRaDIO0_EXTI_IRQn EXTI9_5_IRQn
#define LoRaDIO2_Pin GPIO_PIN_7
#define LoRaDIO2_GPIO_Port GPIOB

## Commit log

2026-02-09 inital commit
    [Accelerometer.kicad_sch, Barometer.kicad_sch, Can_transceiver.kicad_sch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]
2026-02-09 began fixing schematic added barometer
    [Barometer.kicad_sch, Drogue.kicad_sch, FlashSd.kicad_sch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]
2026-02-09 Added SD SPI reader, Fixed file structure
    [Accelerometer.kicad_sch, Barometer.kicad_sch, Can_transceiver.kicad_sch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]
2026-02-09 finished sensor schematics, added datasheets organized files
    [Accelerometer.kicad_sch, Drogue.kicad_sch, GPS1.kicad_sch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]
2026-02-10 added LCSC numbers and footprint values, need to connect schemeatic pins, then can start layout
    [Accelerometer.kicad_sch, Barometer.kicad_sch, Can_transceiver.kicad_sch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]
2026-02-11 started lora schematic all pcb parts should be included
    [Accelerometer.kicad_sch, Barometer.kicad_sch, Can_transceiver.kicad_sch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]
2026-02-11 added sx1262x according to refrence
    [LoRa.kicad_sch]
2026-02-12 fixed symbols and added diodes to power input before ldo
    [Accelerometer.kicad_sch, Barometer.kicad_sch, Drogue.kicad_sch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]
2026-02-12 added lora correct and organizing sheet pins
    [Accelerometer.kicad_sch, Barometer.kicad_sch, Can_transceiver.kicad_sch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]
2026-02-12 finished pin assignments and ran ERC all good ready for layout
    [Accelerometer.kicad_sch, Barometer.kicad_sch, Can_transceiver.kicad_sch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]
2026-02-12 Added Flash memory
    [FlashMemory.kicad_sch, MCU.kicad_sch, flightcomputer2.kicad_sch]
2026-02-16 finalizing layout
    [flightcomputer2.kicad_pcb]
2026-02-16 first layout need to go over schematic
    [Accelerometer.kicad_sch, Barometer.kicad_sch, Drogue.kicad_sch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]
2026-02-18 began routing, need layout approval
    [Drogue.kicad_sch, flightcomputer2.kicad_pcb, power.kicad_sch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]
2026-02-19 finalizing layout/making it look nice
    [flightcomputer2.kicad_pcb]
2026-02-19 layout updated finalizing routing
    [flightcomputer2.kicad_pcb]
2026-02-22 finished routing pending final review
    [flightcomputer2.kicad_pcb]
2026-02-24 Updated PCB
    [flightcomputer2.kicad_pcb]
2026-02-26 fixing DRC Warnings updated USBC footprint/schematic, did impedance matching for the trace from rfm95 to antenna connector fixed resistor on flash memeory
    [FlashSd.kicad_sch, Pyro.kicad_sch, flightcomputer2.kicad_pcb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]
2026-02-26 added final lcsc parts
    [FlashSd.kicad_sch, power.kicad_sch, usb_type_c_sch.kicad_sch]
2026-03-11 added aux pyro added reverse polarity protection re routed just need to clean up and check pin assignments
    [Accelerometer.kicad_sch, AuxPyro.kicad_sch, Barometer.kicad_sch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]
2026-03-12 layout completed added testpoints and verified mosfet ect
    [AuxPyro.kicad_sch, Drogue.kicad_sch, MCU.kicad_sch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]
2026-03-12 added comments, awaiting review
    [Accelerometer.kicad_sch, AuxPyro.kicad_sch, Barometer.kicad_sch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]
2026-03-14 updated pcb removed islands that could act as antennas
    [flightcomputer2.kicad_pcb]
2026-03-19 ran drc no warnings/errors
    [flightcomputer2.kicad_pcb]
2026-03-22 reviewed schematic and pcb and replaced part numbers, added and named datasheets into document folder
    [IMU.kicad_sch, LoRa.kicad_sch, MCU.kicad_sch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]
2026-03-22 accidentially had drivers in gitignore
2026-03-23 updated to KiCad 10.0, updated .gitignore
    [Accelerometer.kicad_sch, AuxPyro.kicad_sch, Barometer.kicad_sch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]
2026-03-24 updated stlink
    [Accelerometer.kicad_sch, AuxPyro.kicad_sch, Barometer.kicad_sch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]
2026-03-24 Began BMP388 driver spi functions
2026-03-25 updated Schematic for final order
    [MCU.kicad_sch, flightcomputer2.kicad_pcb]
2026-04-01 added drivers from stm for accel and imu, updated documents folders with pdfs for periferals
2026-04-01 added a handler struct in .h file and began writing HAL layer code including init, and read and write functions using hal the driver takes care of everything else just need to define spi read and wri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
2026-04-02 ported driver for IMU, wrote HAL, settings are made for rocket, 2000dps gy and 16g xl settings settings can be changed in the init function
2026-04-04 finished framework for CAN driver, normal transmit function and a recive function that runs of interupt
2026-04-05 finished lora driver main functions
2026-04-08 Fixing ldo pinout, updated lora drivers need to still write final function such as lora sleep ect
    [flightcomputer2.kicad_pcb, flightcomputer2.kicad_sch, power.kicad_sch]
2026-04-21 fixed STLINK connector with correct pin mapping
    [MCU.kicad_sch, flightcomputer2.kicad_pcb, usb_type_c_sch.kicad_sch]
2026-04-23 Flashed to STM spi seems to be working however ldo may have fried sensors will workup on second board
2026-04-23 updated pcb edits
    [flightcomputer2.kicad_pcb]
2026-05-06 fixed spi prescaler rates now tx lora works and sensors work
    [Code.ioc, LoRa.c, Lora_App.c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]
2026-05-12 updated cmake to include crc16.c, added all correct includes, in the telemetry side i added a empty 4 byte buffer before the transmission because the library for the reciver has a 4 byte buffer that 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
    [Lora_App.c, telemetry.c]
2026-05-12 began writing code for sd card logger used git refrence writing glue myself used a struct instead of defines for the pin and hspi definitions
2026-05-19 sd driver fmount implemented but wiring on board incorrect so will have to verify next bring up
2026-05-19 updated flash memory driver, need to check with new ldo, added to cmake,
2026-05-25 flight state machine and kalman filter implementation
2026-05-27 kalman filter works, transmits over lora
2026-06-03 has AI audit accross codebase to find issues, and document in docs folder, C4, M1, C2 have been addressed see docs for definitions
    [BMP388.c, h3lis331dl_hal.c, lsm6dsox_hal.c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]
2026-06-03 added propper error haneling for accel and imu in platform read and write, added debug cmake build definitions in flight sensors
    [flight_sensors.c, h3lis331dl_hal.c, lsm6dsox_hal.c]
2026-06-03 updated FSM and fixed blocking loop in state apogee if apogee is less than main deployment altitude
    [flight_state.c]
2026-06-03 updated fsm struct to reflect counters for checking sample lengths for apogee, boost and coast, moved away from static calls in the actual fsm as this can cause portibility issues
2026-06-03 added flag for pyro commands, added error handler pyro will be set to reset so they dont fire added debug in main
    [main.c, pyro.c, telemetry.c]
2026-06-03 changed all drouges to correct spelling drogue
    [Code.ioc, flight_state.c, main.c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]
2026-06-08 added no blocking buzzer functions addded guards to pyro for pop tests
    [flight_config.h, flight_state.c, indicators.c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]
2026-06-08 fixed prescaler rates for spi 2 and 3 in cubemx and regenereated the code
    [Code.ioc, main.c]
2026-06-08 updated final spi prescaler values
2026-06-08 added watchdog, fixed pyro dead code, fixed timeouts, need to fix fsm flags for confrim samples
    [Code.ioc, flight_config.h, flight_state.c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]
2026-06-08 added read flags for baro and imu so fsm confirmation counters will increment on every read not every tick
2026-06-09 added refrence document, fixed flight config dead define
    [flight_config.h]
2026-06-09 fixed cubemx driver issues
    [main.c, pyro.c, telemetry.c]
2026-06-09 arm and disarm works, can send pyro commands, need to do HIL testing with data to see if it goes throug all other states correctly
    [main.c, telemetry.c]
2026-06-10 ran HIL data, flight computer works as intended, added scripts for flash for debug and flash for release, nested all print statements into debug, tuned baro for kalman filter

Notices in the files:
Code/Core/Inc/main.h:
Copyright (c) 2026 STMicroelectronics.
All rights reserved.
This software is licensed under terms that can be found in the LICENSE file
